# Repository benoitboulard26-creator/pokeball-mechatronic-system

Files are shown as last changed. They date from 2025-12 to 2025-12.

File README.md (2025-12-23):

# Pokéball Mechatronic System

A complete **mechatronic project** combining **mechanical design**, **electronics**, and **embedded software** to create a **3D-printed Pokéball that opens and closes at the press of a button** using a servo motor.

<p align="center">
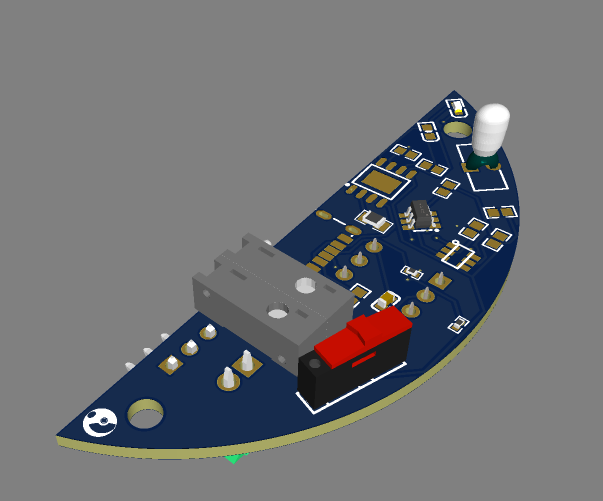
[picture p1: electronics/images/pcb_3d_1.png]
  
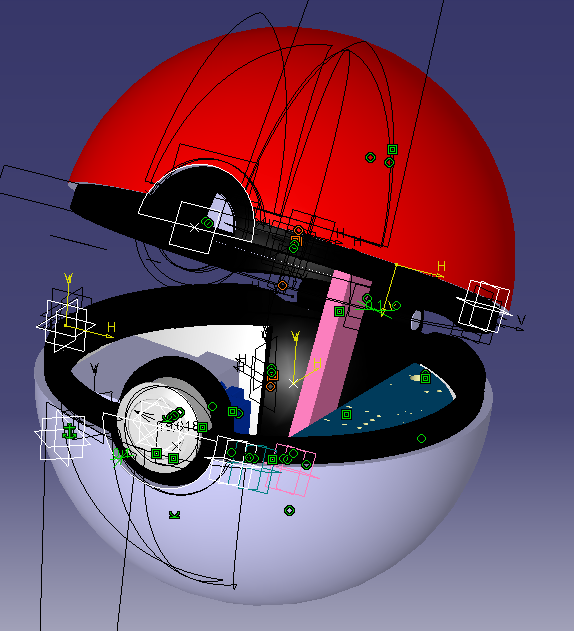
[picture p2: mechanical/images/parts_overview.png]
  
  
</p>

<p align="center">
  <em>PCB design — 3D printed mechanical parts — Functional open/close animation</em>
</p>

---

## Project Motivation

This project was driven by the desire to build a **real, functional object** that combines:
- mechanical design
- electronics design
- embedded programming  

The Pokéball was chosen as a **compact, recognizable, and mechanically interesting object**, requiring:
- precise tolerances
- reliable actuation
- low-power embedded control  

The goal was not only to make it work, but to make it **manufacturable, reproducible, and cleanly documented**.

---

## System Overview

The system is composed of:
- A **3D-printed mechanical assembly** allowing smooth opening and closing
- A **custom PCB** powered by a rechargeable battery
- An **embedded microcontroller** controlling a servo motor
- A **push button** used as the user interface

### Functional principle
1. The system is powered by a rechargeable battery  
2. Voltage is boosted from **3.3 V to 5 V**
3. When the button is pressed:
   - the microcontroller toggles its state
   - the servo motor actuates
   - the Pokéball opens or closes accordingly

---

## Design & Development Approach

### Mechanical Design
- Designed entirely in: **CATIA V5**
- Assembly-driven design to validate motion and clearances
- Parts exported and tested for **FDM 3D printing**
- Tolerances adjusted through real-world testing

### Electronics
- PCB designed using: **EasyEDA**
- PCB manufactured by: **JLCPCB**
- Battery-powered system with onboard charging via USB-C
- Voltage regulation and boosting for servo compatibility

### Embedded Software
- Firmware written for an: **ATtiny85**
- Manual PWM generation for servo control
- Button debouncing and state toggling
- Simple, deterministic logic adapted to low-resource hardware

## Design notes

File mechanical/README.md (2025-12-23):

# 3D Printed Parts – Technical Notes

## Design & CAD
All parts were designed using: CATIA V5.
The models were created with proper constraints, verified assemblies, and clean geometries.

## Tolerances & Testing
- The parts have been **tested and adjusted with tolerances** suitable for FDM 3D printing.
- They were specifically validated for printing on an**: Ender 3 V3 SE**.
- Fit and assembly were checked after printing.

## Printing Disclaimer
Depending on:
- your printer calibration  
- filament type  
- layer height and extrusion settings  

**minor sanding may be required** to achieve a perfect fit.  
This is normal and expected, as tolerances can vary slightly from one printer to another.

## Illustration

<p align="center">
  
  
</p>

<p align="center">
  <em>Static overview of the printed parts (left) — Functional open/close mechanism animation (right)</em>
</p>

## Recommendations
- Ensure your printer is well-calibrated (steps/mm, flow rate).
- Use standard PLA or PETG profiles as a baseline.
- Light post-processing (sanding) is recommended if parts feel tight.

---

Designed, tested, and prepared with real-world printing constraints in mind.

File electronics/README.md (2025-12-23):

# PCB – Design & Manufacturing Notes

## PCB Design
The PCB was designed using :EasyEDA.
The schematic and layout were fully completed, verified, and prepared for manufacturing.

## Manufacturing
The PCB was ordered and manufactured by :JLCPCB.

## Folder Structure
This directory contains the following subfolders:
- **/3D** → 3D files of the PCB (STEP / 3D visualization)
- **/Gerber** → Gerber files ready for manufacturing
- **/BOM_PnP** → CSV files for:
  - Bill of Materials (BOM)
  - Pick and Place (PnP)

## PCB Overview
The board is powered by a **3.3 V battery**, which is **boosted to 5 V** for the required components.
- Battery charging is handled through a **USB-C port**
- An **:ATtiny85** is used as the main controller
- A **servo motor** is controlled to open and close the Pokéball
- The action is triggered by a **push button**

## Functional Description
1. The PCB is powered from a rechargeable battery  
2. Voltage is boosted from 3.3 V to 5 V  
3. When the push button is pressed:
   - the ATtiny85 processes the input
   - the servo motor is actuated
   - the Pokéball opens or closes accordingly

## PCB Views

<p align="center">
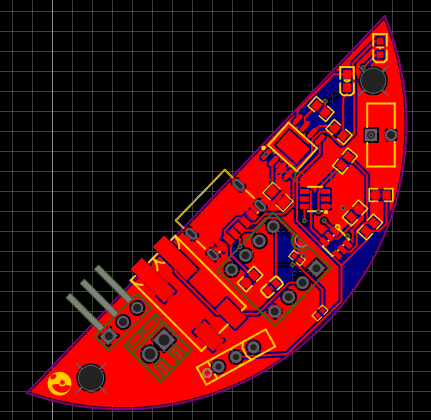
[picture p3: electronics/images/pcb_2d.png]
  
  
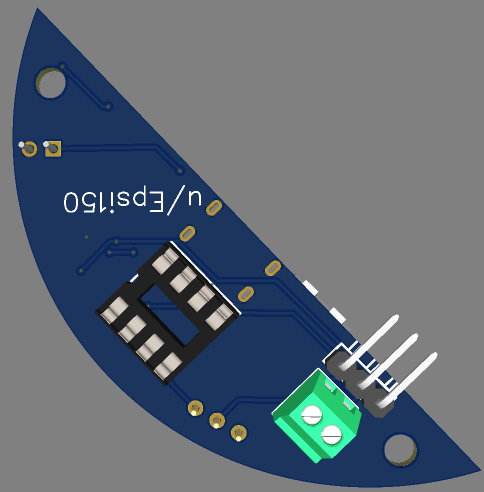
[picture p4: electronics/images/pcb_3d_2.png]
  
</p>

<p align="center">
  <em>2D View — 3D Top View — 3D Bottom View</em>
</p>

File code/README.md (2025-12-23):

# Firmware – ATtiny85 Control Code

## Overview
This folder contains the firmware used to control the PCB functionality.
The code is written for an **ATtiny85** microcontroller and is responsible for handling user input and servo motor control.

## Hardware Mapping
The following pin configuration is used on the ATtiny85:

| Function | ATtiny85 Pin | Arduino Pin |
|---|---|---|
| Servo signal | PB0 | Pin 0 (Pin 5) |
| Push button | PB3 | Pin 3 (Pin 2) |

- The push button uses the **internal pull-up resistor**
- The servo motor is driven using a **manually generated PWM signal**

## Functional Description
- The system waits for a **push button press**
- Each button press toggles the servo position:
  - One position corresponds to the Pokéball **open state**
  - The other corresponds to the **closed state**
- A counter is used to alternate between positions
- Basic software debouncing is implemented

## Servo Control Strategy
- The servo signal is generated **manually**, without using a dedicated servo library
- PWM characteristics:
  - Period: ~20 ms
  - Pulse width:
    - ~1500 µs → neutral / mid position
    - ~450 µs → extreme position
- This approach ensures:
  - Low memory usage
  - Full compatibility with the ATtiny85

## Button Handling
- The button is read using `INPUT_PULLUP`
- A state change from **HIGH → LOW** triggers an action
- A short delay is used to limit switch bouncing

## Notes & Limitations
- Servo angle values may need adjustment depending on:
  - Servo model
  - Mechanical constraints
- Timing is handled using `delay()` and `delayMicroseconds()`, which is sufficient for this application but not intended for multitasking systems

## Compilation & Upload
- Compatible with Arduino IDE using an ATtiny85 core
- Ensure correct clock configuration before uploading
- Recommended to test servo motion without mechanical load first

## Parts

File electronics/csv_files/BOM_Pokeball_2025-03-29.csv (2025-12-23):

ID | Name | Designator | Footprint | Quantity | Manufacturer Part | Manufacturer | Supplier | Supplier Part | Price
1 | 10uF | C1 | 0603 | 1 | CL10A106MP8NNNC | SAMSUNG | LCSC | C85713 | 0.005
2 | 100nF | C2,C3 | 0603 | 2 | 0603B104K250 | WTC | LCSC | C83054 | 0.003
3 | 1K | R1,R2,R4 | 0603 | 3 | ERJ3GEYJ102V | PANASONIC | LCSC | C180848 | 0.005
4 | 100Ω | R5 | 0603 | 1 | 0603WAJ0101T5E | UniOhm | LCSC | C25201 | 0.001
5 | 100nF | C4 | C0603 | 1 | GCJ188R71H104KA12D | muRata(村田) | LCSC | C161115 | 0.025
6 | GREEN | LED1 | LED-0603 | 1 | LTST-C193TGKT-5A | LITEON | LCSC | C12065 | 0.032
7 | TP4056 | U1 | SOP-8_EP_150MIL | 1 | TP4056 | TOPPOWER | LCSC | C16581 | 0.177
8 | DW01A | U2 | SOT-23-6L | 1 | DW01A | PUOLOP | LCSC | C351410 | 0.032
9 | TYPE-C 6PIN | U5 | USB-C-SMD | 1 | TYPE-C 6PIN | SHOU HAN(首韩) | LCSC | C7507406 | 0.046
10 | 2834006-2 | CN1 | CONN-SMD_2834006-2 | 1 | 2834006-2 | TE Connectivity(泰科电子) | LCSC | C86483 | 0.473
11 | FS8205A_C908265 | Q2 | SOT-23-6_L2.9-W1.6-P0.95-LS2.8-BR | 1 | FS8205A | FUXINSEMI(富芯森美) | LCSC | C908265 | 0.054
12 | 10KΩ | R6 | RES-TH_L8.0-W2.8-P2.54-D0-6 | 1 | NTCLE101E3C90173 | VISHAY(威世) | LCSC | C143692 | 1.183
13 | BSI-10_C2985934 | SW1 | SW-TH_BSI-10 | 1 | BSI-10 | SM Switch | LCSC | C2985934 | 0.759
14 | VLMS1300-GS08 | LED2 | LED0603-R-RD_RED | 1 | VLMS1300-GS08 | VISHAY(威世) | LCSC | C83242 | 0.076
15 | 10kΩ | R7 | R0805 | 1 | ERJ6ENF1002V | PANASONIC(松下) | LCSC | C169253 | 0.007
16 | 5.1kΩ | R3,R8 | R0402 | 2 | RTT025101FTH | RALEC(旺诠) | LCSC | C103079 | 0.001
17 | XY308-2.54-2P | U6 | CONN-TH_XY308-2.54-2P | 1 | XY308-2.54-2P | XINLAIYA(新莱亚) | LCSC | C557685 | 0.232
18 | PZ2.54-1*3-WZ | PIN_SERVO | HDR-TH_3P-P2.54-H-M-W7.7-P | 1 | PZ2.54-1*3-WZ | ZHOURI(洲日) | LCSC | C5360904 | 0.027
19 | AtTiny85 | U3 | DIP-8_L10.2-W10.2-P2.54-LS7.6-BL | 1 | DS1009-08AT1NX-0A2 | CONNFLY | LCSC | C72124 | 0.026

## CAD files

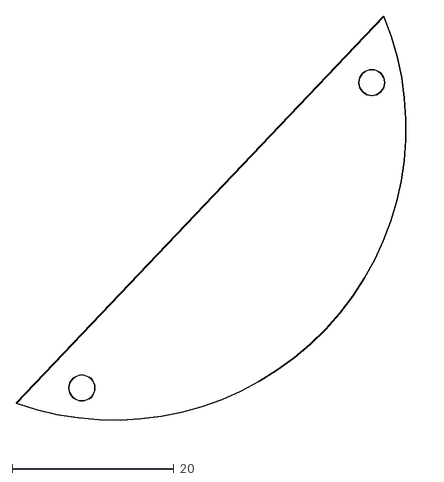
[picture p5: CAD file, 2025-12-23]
electronics/3d_files/PCB.dxf
50.9 x 52.7

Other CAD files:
mechanical/catia_files/ASSEMBLAGE.CATProduct
mechanical/catia_files/Axe_de_rotation.CATPart
mechanical/catia_files/Board.CATPart
mechanical/catia_files/Coque_basse.CATPart
mechanical/catia_files/Coque_haute.CATPart
mechanical/catia_files/PCB_STEP.CATProduct
mechanical/catia_files/Part19.CATPart
mechanical/catia_files/SQUELTTE_RING_BAS.CATProduct
mechanical/catia_files/SQUELTTE_RING_HAUT.CATProduct
mechanical/catia_files/User Library-SG90.CATPart
mechanical/catia_files/bras_extension.CATPart
mechanical/catia_files/bras_servov2.CATPart
mechanical/catia_files/ring.CATPart
mechanical/catia_files/ring_haut.CATPart
mechanical/catia_files/servo_bras.CATPart
mechanical/catia_files/squelette_ring-nouvelle-revolution.CATPart
mechanical/catia_files/squelette_ring.CATPart

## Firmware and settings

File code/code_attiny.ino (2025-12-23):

const int pin_servo = 0;     // PB0 = pin 5
const int pin_bouton = 3;    // PB3 = pin 2

int compteur = 0;
int switch_state;
int last_switch_state = HIGH;

void setup() {
  pinMode(pin_bouton, INPUT_PULLUP);  // Bouton avec résistance pull-up interne
  pinMode(pin_servo, OUTPUT);         // Configure PB0 en sortie pour le servo
}

void loop() {
  switch_state = digitalRead(pin_bouton);

  if (switch_state == LOW && last_switch_state == HIGH) {
    compteur++;
    delay(150); // anti-rebond
  }

  // Détermination de la largeur d'impulsion selon le compteur
  int pulseWidth;
  if (compteur % 2 == 0) {
    pulseWidth = 1500;  // Position milieu (~90°)
  } else {
    pulseWidth = 450;   // Position extrême (~0°)
  }

  // Génération manuelle du signal PWM pour 1 cycle (20 ms)
  digitalWrite(pin_servo, HIGH);
  delayMicroseconds(pulseWidth);
  digitalWrite(pin_servo, LOW);
  delay(20 - pulseWidth / 1000);  // Compléter les 20 ms

  last_switch_state = switch_state;

  delay(50);  // Délai pour ne pas saturer le bouton
}

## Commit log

2025-12-23 Added catia files
    [ASSEMBLAGE.CATProduct, Axe_de_rotation.CATPart, Board.CATPart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]
2025-12-23 added stl exports folder
2025-12-23 Add technical notes for 3D printed parts
    This README provides technical notes on the design, tolerances, and printing recommendations for 3D printed parts.
2025-12-23 Update README with design software and printer model
2025-12-23 Format and update README for 3D printed parts
2025-12-23 modified PCB folders Readme's
2025-12-23 Create README.md for PCB design and manufacturing
    Added detailed notes on PCB design, manufacturing, and functionality.
2025-12-23 Add README for ATtiny85 firmware control code
    Added a README file detailing firmware for ATtiny85 control code, including hardware mapping, functional description, servo control strategy, button handling, notes, and compilation instructions.
